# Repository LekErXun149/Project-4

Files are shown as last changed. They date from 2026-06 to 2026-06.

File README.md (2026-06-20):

# Bin Weighting System 
Weighting different type of SKU to output the correct quantity for each SKU\
Done by: Team 5
1. Gerald Goh Xuan Chee: Project Leader & Lead Software Engineer\
●	Project Management: Directed the 13-week development timeline, managed team task allocation, and ensured all system requirements met CEVA Logistics' standards.\
●	Computer Vision & AI (YOLOv8s): Took primary ownership of training the YOLOv8s model for SKU identification and configured the drivers for the dual-camera system.\
●	ROS2 Middleware Architecture: Implemented the modular ROS2 (Jazzy) node structure and the integration logic that synchronized vision data with weight inputs.
2. Lek Er Xun: Lead Mechanical Designer & Sensing Developer\
●	Precision CAD Modeling: Utilized SolidWorks to design the bin structure (MM01) and performed interference checks to ensure a seamless physical assembly.\
●	Load Cell Software Development: Authored the firmware for weight sensing, including the calibration of the 4-load-cell array and the communication protocol for the ADC modules.\
●	Rapid Prototyping: Managed the 3D printing of custom sensor mounts and spacers to ensure exact mechanical tolerances.
3. Tung Ming Xuan: Lead Validation & Fabrication Specialist\
●	System Testing & QA: Designed and executed the 50+ test cycles to verify the 1% relative accuracy and 95% SKU identification success rates.\
●	Mechanical Fabrication: Managed the manual construction and material preparation of the bin frame, ensuring the physical build matched the SolidWorks specifications.\
●	Dataset Management: Responsible for the SKU onboarding process, accurately recording the "ground truth" weights and visual profiles for the identification model.
4. Loh Sook Xian Rosalind: Procurement & Electrical Assembly Lead\
●	Electrical Hardening: Executed the soldering of the HX711 amplifier modules and core circuitry to move the project from volatile jumper wires to a permanent, vibration-resistant setup.\
●	Financial Accountability: Managed the Bill of Materials (BOM) and direct cost tracking to ensure the project stayed within the $500.00 budget.\
●	Sustainability Assessment: Conducted the evaluation of material choices and system power efficiency for the final report.
5. Alson Lim Chin Meng: Hardware Operations & Mechanical Support\
●	Hardware Environment Deployment: Responsible for the physical setup and OS configuration of the Raspberry Pi 4 to provide a stable platform for the system middleware.\
●	Power & Connectivity Management: Integrated the powered USB 3.0 hub to provide a consistent 5V supply to the cameras, preventing hardware resets.\
●	Thermal Management: Installed the active cooling system (heatsink and fan) to ensure the processor maintained performance during high-load operations.\
●	Fabrication Support: Assisted in the mechanical assembly and material cutting for the bin weighting structure.

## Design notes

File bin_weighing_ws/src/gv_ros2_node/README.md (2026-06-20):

## gv camera ros2 node

## RUN
```sh
 
ros2 launch gv_ros2 gv_camera.launch.py 

```

## 1.Dependency library

```sh
1. sudo cp ./res/50-myusb.rules /etc/udev/rules.d/
2. sudo udevadm control --reload-rules
3. sudo /etc/init.d/udev restart
4. sudo apt install libusb-1.0-0-dev libuvc-dev
5. sudo apt install libyaml-cpp-dev
```

## 2.Compile

```sh
2.1 cd gv_ros2
2.2 colcon build --packages-select gv_ros2
```

## 3.Running

```sh
3.1  . install/local_setup.sh
3.2  ros2 launch gv_ros2 gv_ros2.launch.py
```

## 4.Config params

```sh
### camera config

# set camera streams status(0 (close), 1(ir), 2(depth), 3(color), 4(ir+depth), 5(color+depth))
stream_status: 5 

# publish pointcloud
publish_pointcloud: true

# depth align to color
align_depth_to_color: false

# set camera bandwidth(0, 512,	1020,	1536,	2040,	2556,	3060)
band_width: 3060

# the max depth distance  of pointcloud
max_distance: 4.0

# show image by opencv
show_image: false

# output stream log
show_data_size: false
```
## 5.Precautions
```sh
5.1 IR data stream and depth data stream cannot be enabled at the same time.

5.2 IR data stream and color data stream cannot be enabled at the same time.
```

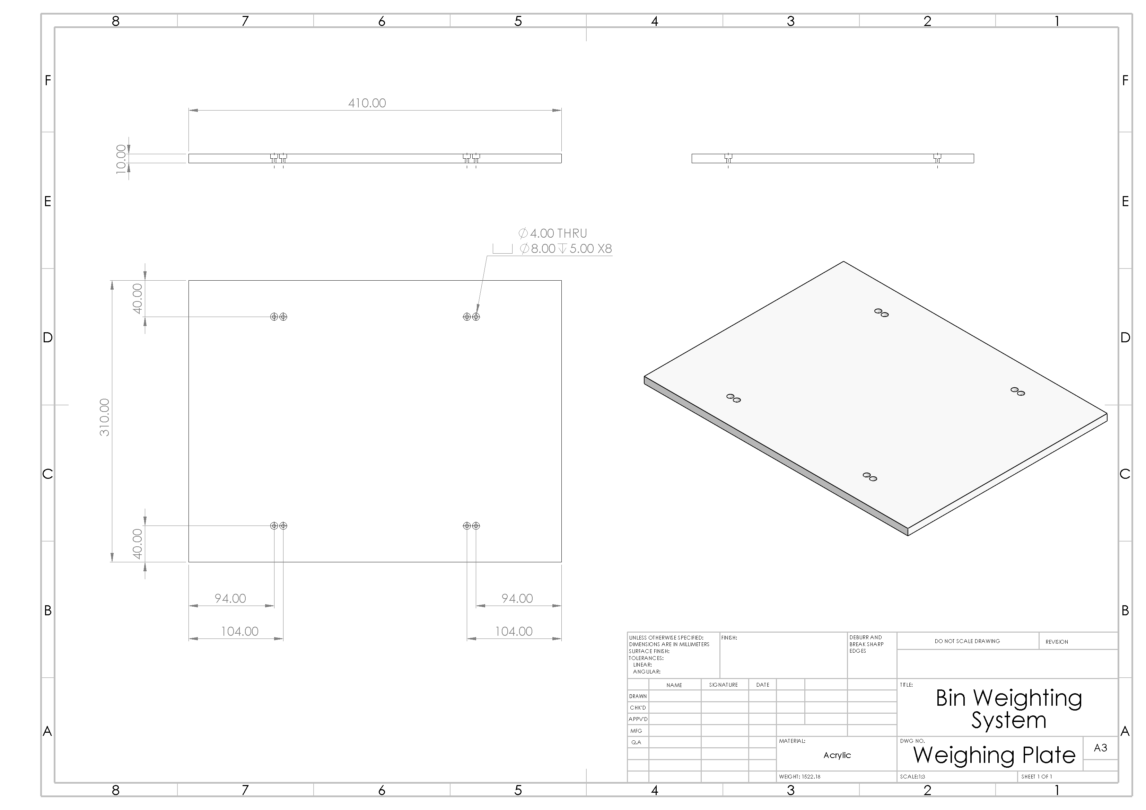
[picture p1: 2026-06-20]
CAD/Drawing/Weighing Plate.PNG

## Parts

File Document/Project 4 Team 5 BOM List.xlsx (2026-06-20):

Module: | RSE2109-Project 4 [2025/26 T2]
Done By: | Team 5
Member: | Alson Lim Chin Meng (2403433)
 | Gerald Goh Xuan Chee (2400766)
 | Lek Er Xun (2402042)
 | Loh Sook Xian Rosalind (2403415)
 | Tung Ming Xuan (2400842)
Legend
 | Unconfirmed components are highlighted in red
 | Loan components are highlighted in yellow
BOM List
 |  |  |  | Total Cost
Component NO. | Component Name | Qty | Unit Cost ($) | Direct Cost ($) | Indirect Cost ($) | Material | Size (mm) | Submitted By | Confirmed By | Remark | Component Link (Price)
MM01 | Bin Weighting Structure | NIL
MM01A01 | Focatek Depth Camera | 1 | NIL | NIL | 299.00 | NIL | NIL | Lek Er Xun | Rosalind Loh | Loan from school | NIL
MM01A02 | Raspberry Pi Camera Module 3 | 1 | 55.90 | NIL | 55.90 | NIL | NIL | Lek Er Xun | Rosalind Loh | Loan from school | Raspberry Pi Camera Module 3 (https://makersupplies.sg/products/raspberry-pi-camera-3)
MM01A03 | Load Cell Weight Sensor (5Kg) | 4 | 7.40 | 29.60 | NIL | NIL | NIL | Lek Er Xun | Tung Ming Xuan | NIL | 5Kg Load Cell Weight Sensor (https://shopee.sg/Load-Cell-1kg-5kg-10kg-20kg-i.440521573.7989384220)
MM01A03 | Load Cell Weight Sensor (5Kg) | 8 | 7.00 | 56.00 | NIL | NIL | NIL | Lek Er Xun | Tung Ming Xuan | NIL | Physical Purchase
MM01A04 | Raspberry Pi 4 Model B (8GB), 64GB SD Card, Casing with Accessory | 1 | 197.90 | NIL | 197.90 | NIL | NIL | Lek Er Xun | Rosalind Loh | Loan from school | Raspberry Pi 4 Model B (8GB) (https://shopee.sg/Raspberry-Pi-4-B-(-2GB-or-4GB-or-8GB-)-Starter-Kit-(-Power-supply-Premium-Case-Micro-SD-with-noobs-Heatsink)-i.28748863.3204168526)
MM01A05 | NAU7802 ADC Modules | 1 | 11.99 | 11.99 | NIL | NIL | NIL | Lek Er Xun | Tung Ming Xuan | NIL | NAU7802 ADC Modules (https://shopee.sg/DIYMORE-NAU7802-High-Precision-Adc-Module-24-Bit-Adc-Data-Conversion-Pressure-Module-Compatible-With-STEMMA-QT-Qwiic-i.161535507.48705037684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)
MM01A06 | HX711 ADC Modules | 1 | 7.00 | 7.00 | NIL | NIL | NIL | Lek Er Xun | Tung Ming Xuan | NIL | Physical Purchase
MM01A06 | HX711 ADC Modules | 3 | 6.00 | 18.00 | NIL | NIL | NIL | Lek Er Xun | Tung Ming Xuan | NIL | Physical Purchase
MM01A07 | ORICO 4 Port USB3.0 HUB with Power | 1 | 35.00 | 35.00 | NIL | NIL | NIL | Lek Er Xun | Rosalind Loh | NIL | ORICO 4 Port USB3.0 HUB with Power (https://shopee.sg/product/29641888/8511248406)
MM01A08 | USB-A to Type-C Cable | 1 | 7.99 | 7.99 | NIL | NIL | 1500 | Lek Er Xun | Rosalind Loh | NIL | USB-A to Type-C Cable (https://shopee.sg/Ugreen-3A-480Mbps-USB-A-to-Type-C-USB-C-Nylon-Braided-Fast-Charging-Cable-for-Phone-Fans-Tablets-i.64922680.7312481785)
MM01A09 | USB-A to Type-C Cable | 1 | 6.99 | 6.99 | NIL | NIL | 1000 |  |  |  | USB-A to Type-C Cable (https://shopee.sg/Ugreen-3A-480Mbps-USB-A-to-Type-C-USB-C-Nylon-Braided-Fast-Charging-Cable-for-Phone-Fans-Tablets-i.64922680.7312481785)
MM01A10 | Solder Breadboard | 1 | 2.00 | 2.00 | NIL | NIL | 1500 | Lek Er Xun | Rosalind Loh | NIL | Physical Purchase
MM01B01 | Plywood Sheet | 1 | 8.18 | 8.18 | NIL | Plywood | 360x410x18 | Lek Er Xun | Tung Ming Xuan | Require Sanding and drilling | Plywood Sheet (https://shopee.sg/18mm-plywood-40x50-cm-Multiplex-18-mm-50x40-cm-MC-Uty-Grade-A-Wood-Sheet-i.965491602.28063803444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)
MM01B02 | Acrylic Sheet | 1 | 39.88 | 39.88 | NIL | Acrylic | 310x410x10 | Lek Er Xun | Tung Ming Xuan | Require Sanding and drilling | Acrylic Sheet (https://shopee.sg/product/438933164/8353279058?d_id=003a3&uls_trackid=54tbj4uo00pn)
MM01C01 | Square Hollow Profile | 1 | 14.10 | NIL | 14.10 | Aluminium | 20x20x1000 | Lek Er Xun | Rosalind Loh | Loan from school | Square Hallow Profile (https://sg.misumi-ec.com/vona2/detail/110300467270?HissuCode=HFHQ2020-2-1000)
MM01C02 | T-Slot Profile | 1 | 1.04 | NIL | 1.04 | Aluminium | 20x20x200 | Lek Er Xun | Rosalind Loh | Loan from school | T-Slot Profile (https://sg.misumi-ec.com/vona2/detail/110310153359?HissuCode=LCF6-2020-200)
MM01C03 | L Bracket (Profile Mount) | 3 | 7.58 | NIL | 22.74 | Aluminium | 32x32x18 | Lek Er Xun | Rosalind Loh | Custom cut from angle bar (Scape Metal) | L Bracket (Profile Mount) (https://sg.misumi-ec.com/vona2/detail/110300544720?HissuCode=LRA3-A32-B32-L20)
MM01C04 | Hex Socket Screw (Profile Mount / Load Cell Mount) | 19 | 0.22 | NIL | 4.18 | Stainless Steel | M4x20 | Lek Er Xun | Rosalind Loh | Loan from school (3 for Profile Mount 16 for Load Cell Mount) | Hex Socket Screw (Profile Mount) (https://sg.misumi-ec.com/vona2/detail/221000551286?HissuCode=CSH-SUS-M4-20)
MM01C05 | Hex Socket Screw (Profile Mount) | 4 | 0.10 | NIL | 0.40 | Stainless Steel | M4x30 | Lek Er Xun | Rosalind Loh | Loan from school | Hex Socket Screw (Profile Mount) (https://sg.misumi-ec.com/vona2/detail/110310861029?HissuCode=E-GSCB4-30)
MM01C06 | Hex Socket Screw (Slider Mount / Depth Camera Mount) | 6 | 0.04 | NIL | 0.24 | Stainless Steel | M3x10 | Lek Er Xun | Rosalind Loh | Loan from school (4 for Slider Mount 2 for Depth Camera Mount) | Hex Socket Screw (Slider Mount) (https://sg.misumi-ec.com/vona2/detail/110310861029?HissuCode=E-GSCB3-10)
MM01C07 | Hex Socket Screw (Slider Mount) | 2 | 0.10 | NIL | 0.20 | Stainless Steel | M5x12 | Lek Er Xun | Rosalind Loh | Loan from school | Hex Socket Screw (Slider Mount) (https://sg.misumi-ec.com/vona2/detail/110310861029?HissuCode=E-GSCB5-12)
MM01C08 | Hex Socket Screw (Slider Mount / Depth Camera Mount) | 3 | 0.10 | NIL | 0.30 | Stainless Steel | M5x16 | Lek Er Xun | Rosalind Loh | Loan from school (2 for Slider Mount 1 for Depth Camera Mount) | Hex Socket Screw (Slider Mount) (https://sg.misumi-ec.com/vona2/detail/110310861029?HissuCode=E-GSCB5-16)
MM01C09 | Hex Nuts (Camera Mount) | 7 | 0.02 | NIL | 0.14 | Stainless Steel | M4x3 | Lek Er Xun | Rosalind Loh | Loan from school | Hex Nuts (Camera Mount) (https://sg.misumi-ec.com/vona2/detail/110311012769?HissuCode=E-GSLBNR4)
MM01C10 | Hex Nuts (Slider Mount) | 4 | 0.02 | NIL | 0.08 | Stainless Steel | M3x1.8 | Lek Er Xun | Rosalind Loh | Loan from school | Hex Nuts (Slider Mount) (https://sg.misumi-ec.com/vona2/detail/110311012769?HissuCode=E-GSKNTR3)
MM01C11 | T-Nuts (Slider Mount / Depth Camera Mount) | 3 | 1.25 | NIL | 3.75 | Stainless Steel | M5 | Lek Er Xun | Rosalind Loh | Loan from school (2 for Slider Mount 1 for Depth Camera Mount) | T-Nuts (Slider Mount) (https://sg.misumi-ec.com/vona2/detail/110302608140?HissuCode=SHNTU5-5)
MM01C12 | Washer (Weight Sensor) | 32 | 0.38 | NIL | 12.16 | Stainless Steel | M4x0.8 | Lek Er Xun | Rosalind Loh | Loan from school | Washer (Weight Sensor) (https://sg.misumi-ec.com/vona2/detail/110310394559?HissuCode=C-WSSA8-4-3)
MM01D01 | Profile Joint Mount | 1 | NIL | NIL | NIL | PLA | NIL | Lek Er Xun | Rosalind Loh | 3D printed | NIL
MM01D02 | Depth Camera Mount | 1 | NIL | NIL | NIL | PLA | NIL | Lek Er Xun | Rosalind Loh | 3D printed | NIL
MM01D03 | Raspberry Pi Camera Module 3 Mount | 1 | NIL | NIL | NIL | PLA | NIL | Lek Er Xun | Rosalind Loh | 3D printed | NIL
MM01D04 | HX711 ADC Modules Mount | 1 | NIL | NIL | NIL | PLA | NIL | Lek Er Xun | Rosalind Loh | 3D printed | NIL
MM01D05 | Raspberry Pi 3 Camera Mount | 1 | NIL | NIL | NIL | PLA | NIL | Lek Er Xun | Rosalind Loh | 3D printed | NIL
MM01D06 | USB Port Hub Mount | 1 | NIL | NIL | NIL | PLA | NIL | Lek Er Xun | Rosalind Loh | 3D printed | NIL
MM01E01 | Heatsink with Fan | 1 | 13.21 | 13.21 | NIL | NIL | 40x40x10 | Lek Er Xun | Rosalind Loh | NIL | Heatsink with Fan (https://shopee.sg/YSIDO-30mm-40mm-High-RPM-Fan-Powerful-Storms-Rapid-Heatsink-Metal-Cooling-With-Holder-for-1-8-1-10-1-12-ARRMA-Traxxas-HSP-RC-Car-i.500812033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)
MM01E02 | Thermal Pad | 1 | 2.49 | 2.49 | NIL | NIL | 22x70x0.5 | Lek Er Xun | Rosalind Loh | NIL | Thermal Pad (https://shopee.sg/TEUCER-M.2-SSD-Thermal-Pad-10.8W-mk-CPU-Graphics-Card-Heatsink-Motherboard-Heat-Dissipation-Silicone-Pad-70*22mm-For-SSD-i.1102234819.401531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)
MM02A01 | Bin (Small Eight Grid/375) | 1 | 13.08 | 13.08 | NIL | Plastic | 276x380x85 | Lek Er Xun | Rosalind Loh | NIL | Bin (Small Eight Grid/375) (https://shopee.sg/product/1218344199/26581424138)
MM03A01 | Storage Box | 1 | 6.32 | 6.32 | NIL | Plastic | NIL | Lek Er Xun | Rosalind Loh | NIL | Physical Purchase
MM04A01 | Scale Weights Calibration Set (1000g) | 1 | 16.24 | 16.24 | NIL | Chrome Plated Steel | NIL | Lek Er Xun | Rosalind Loh | Set with 100g, 200g, 500g weight (Total: 1000g) | Scale Weights Calibration Set (https://shopee.sg/Scale-Weights-Calibration-Tool-Set-Calibrate-100g-200g-500g-with-Box-Calibration-Weights-i.208852974.27250024832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)
MM05A01 | 15.6 Inch LCD Display | 1 | 321.07 | NIL | 321.07 | NIL | NIL | Lek Er Xun | Rosalind Loh | NIL | 15.6 Inch LCD Display (https://sg.cytron.io/c-raspberry-pi-display/p-15-6-inch-cap-touch-ips-1920-1080-hdmi-display)
MM06A01 | 7 Inch LCD Display | 1 | 57.08 | 57.08 | NIL | NIL | NIL | Lek Er Xun | Rosalind Loh | NIL | 7 Inch LCD Display (https://shopee.sg/7-Inch-Portable-Monitor-1024x600-IPS-LCD-HDMI-compatible-VGA-AV-Input-DC-Type-C-Power-Screen-for-PC-Laptop-Camera-TV-Box-DVD-i.1280323195.28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)
MM07A01 | Mini Keyboard | 1 | 14.89 | 14.89 | NIL | NIL | NIL | Lek Er Xun | Rosalind Loh | NIL | Mini Keyboard (https://shopee.sg/-SG-Local-Seller-Mini-Slim-Keyboard-Multimedia-USB-Wired-For-Notebook-Laptop-PC-Computer-i.124596143.15760342491)
MM08A01 | Heat Shrink Kit | 1 | 9.40 | 9.40 | NIL | NIL | NIL | Lek Er Xun | Rosalind Loh | NIL | Physical Purchase
MM09A01 | Double-Sided Tape | 1 | 2.18 | 2.18 | NIL | NIL | NIL | Lek Er Xun | Rosalind Loh | NIL | Physical Purchase
MM10A01 | Cable Tie | 1 | 2.18 | 2.18 | NIL | NIL | NIL | Lek Er Xun | Rosalind Loh | NIL | Physical Purchase
NIL | Product | NIL | NIL | NIL | NIL | NIL | NIL | NIL | NIL | 3D Print | Product
Total: |  |  |  | 359.70 | 933.20
 | Direct Cost (SGD$) | 359.70
 | Indirect Cost (SGD$) | 933.20
 | Total Cost (SGD$) | 1292.90

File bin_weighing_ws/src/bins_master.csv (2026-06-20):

bin_barcode | bin_type | bin_tare_weight | item_name | quantity | unit_weight
BIN001 | 8_compartment | 480 | Cream | 1 | 160
BIN001 | 8_compartment | 480
BIN001 | 8_compartment | 480
BIN001 | 8_compartment | 480
BIN001 | 8_compartment | 480
BIN001 | 8_compartment | 480
BIN001 | 8_compartment | 480
BIN001 | 8_compartment | 480
BIN002 | 8_compartment | 480
BIN002 | 8_compartment | 480
BIN002 | 8_compartment | 480
BIN002 | 8_compartment | 480
BIN002 | 8_compartment | 480
BIN002 | 8_compartment | 480
BIN002 | 8_compartment | 480
BIN002 | 8_compartment | 480
BIN003 | 8_compartment | 480
BIN003 | 8_compartment | 480
BIN003 | 8_compartment | 480
BIN003 | 8_compartment | 480
BIN003 | 8_compartment | 480
BIN003 | 8_compartment | 480
BIN003 | 8_compartment | 480
BIN003 | 8_compartment | 480
BIN004 | 8_compartment | 480
BIN004 | 8_compartment | 480
BIN004 | 8_compartment | 480
BIN004 | 8_compartment | 480
BIN004 | 8_compartment | 480
BIN004 | 8_compartment | 480
BIN004 | 8_compartment | 480
BIN004 | 8_compartment | 480
BIN005 | 8_compartment | 480 | Cream | 1 | 160
BIN005 | 8_compartment | 480
BIN005 | 8_compartment | 480
BIN005 | 8_compartment | 480
BIN005 | 8_compartment | 480
BIN005 | 8_compartment | 480
BIN005 | 8_compartment | 480
BIN005 | 8_compartment | 480

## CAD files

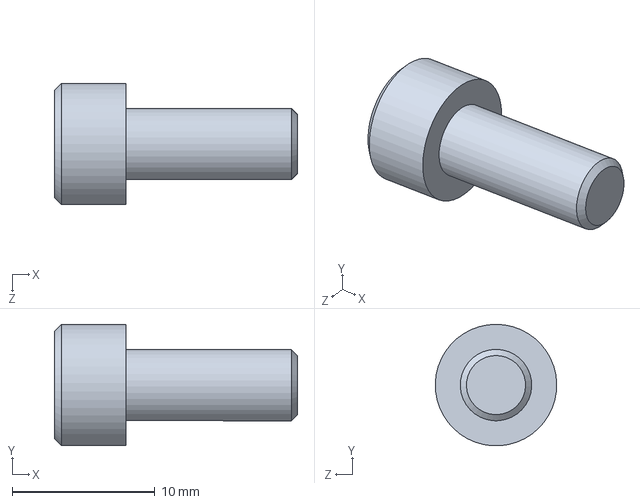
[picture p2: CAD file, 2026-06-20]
CAD/E-GSCB5-12.SLDPRT
17.0 x 8.49 x 8.49 mm

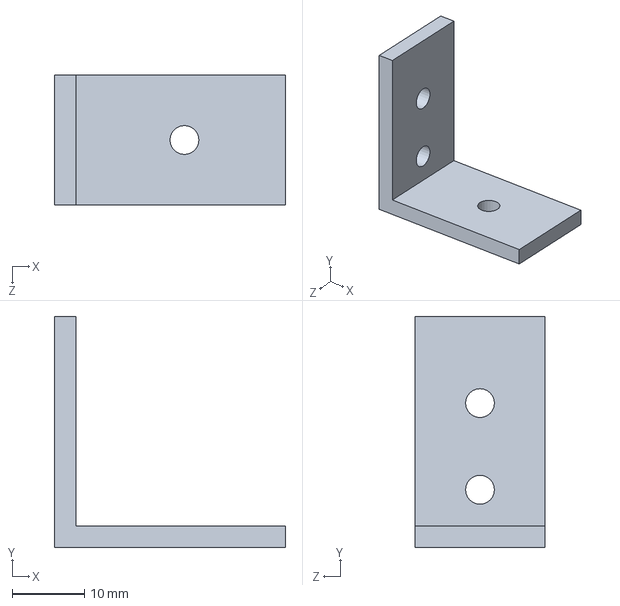
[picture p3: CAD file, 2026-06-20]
CAD/Bracket Front.SLDPRT
32.0 x 32.0 x 18.0 mm

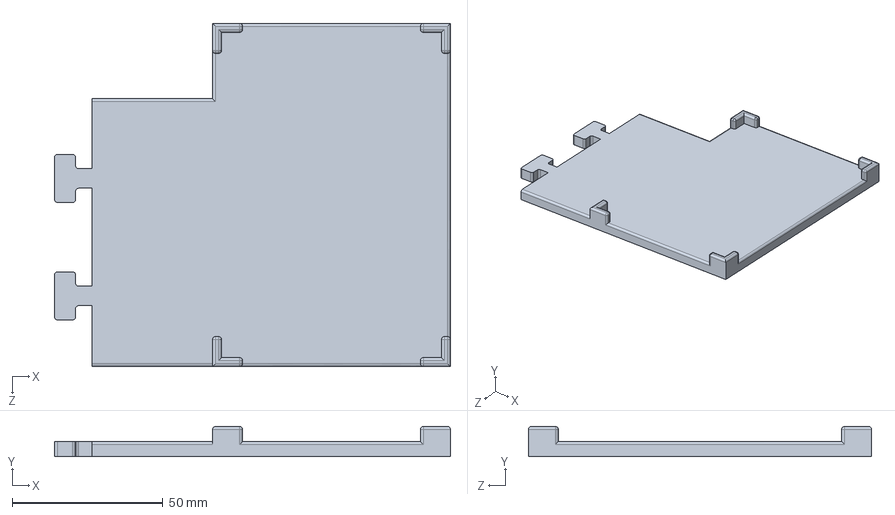
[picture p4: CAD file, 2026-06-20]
CAD/USB Port Hub Mount.SLDPRT
131.5 x 10.0 x 114.0 mm

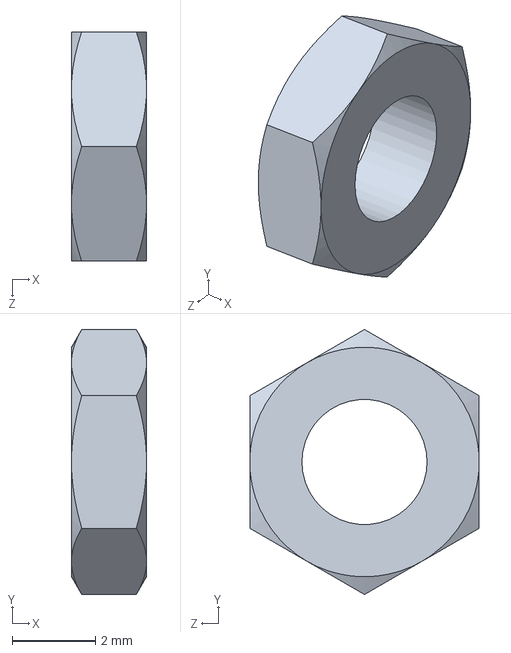
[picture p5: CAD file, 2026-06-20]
CAD/E-GSKNTR3.SLDPRT
1.80 x 6.35 x 5.50 mm

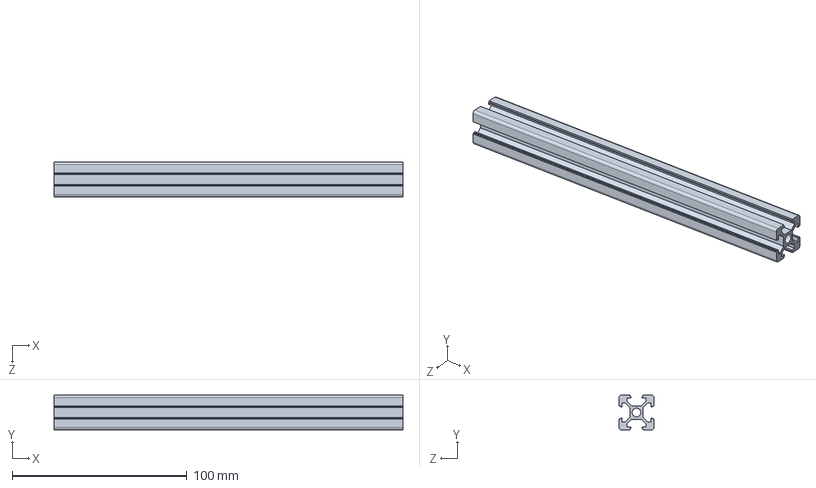
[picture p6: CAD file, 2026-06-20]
CAD/LCF6-2020-200 Profile.SLDPRT
200.0 x 20.0 x 20.0 mm

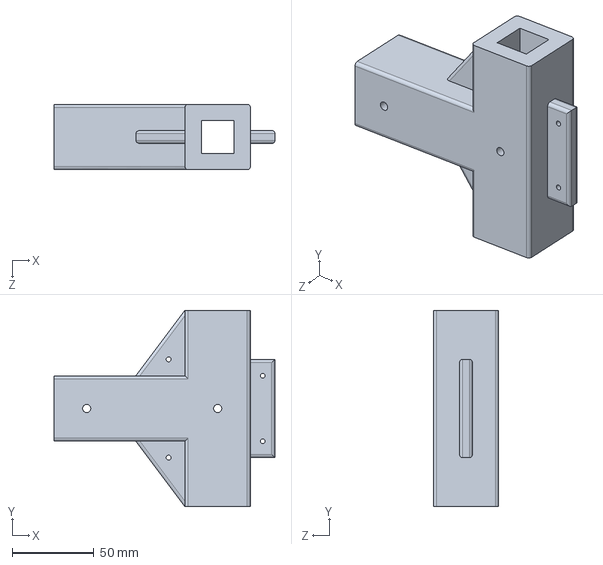
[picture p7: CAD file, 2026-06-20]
CAD/Profile Slider.SLDPRT
135.0 x 120.0 x 40.0 mm

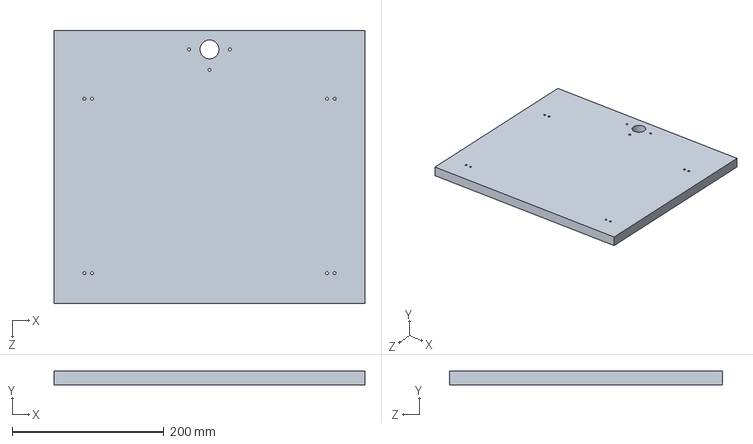
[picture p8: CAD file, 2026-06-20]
CAD/Base.SLDPRT
410.0 x 18.0 x 360.0 mm

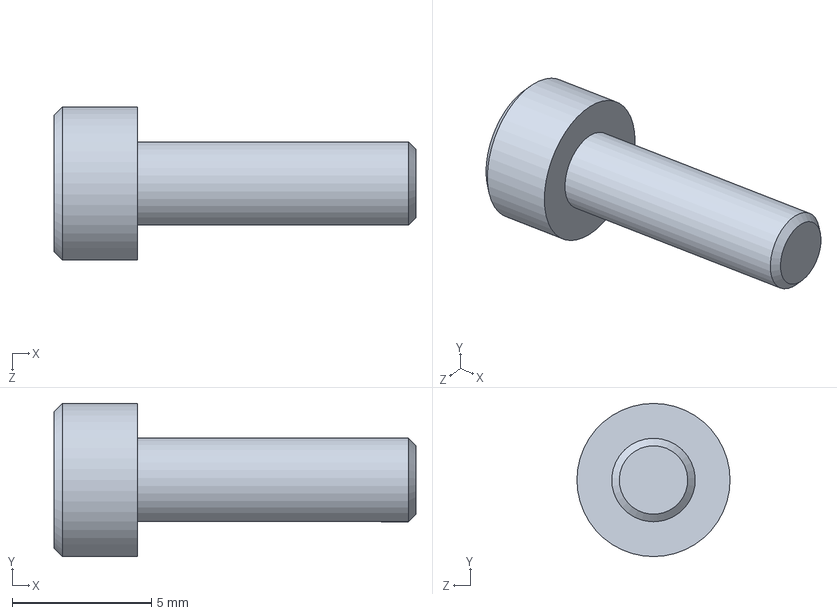
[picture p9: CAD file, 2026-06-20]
CAD/E-GSCB3-10.SLDPRT
13.0 x 5.50 x 5.50 mm

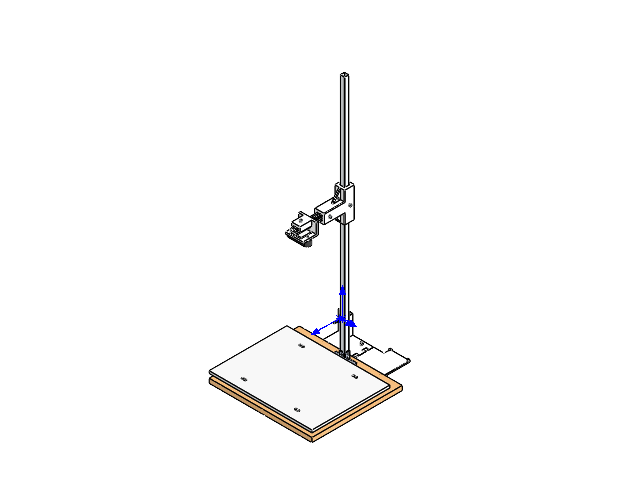
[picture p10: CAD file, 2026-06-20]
CAD/Bin Weighting System.SLDASM
Base
HFHQ2020 Profile
LCF6-2020-200 Profile
Weighing Plate
Load Cell x 4
CSH-STN-M4-20 x 19
SPWF4 Washer x 16
Bracket Front
Bracket LR x 2
E-GSCB4-30 x 4
E-GSLBNR4 x 7
Profile Slider
E-GSCB3-10 x 6
E-GSKNTR3 x 4
E-GSCB5-12 x 2
E-GSCB5-16 x 3
SHNTU5-5 x 3
Heatsink with Fan
Focatek Depth Camera
Depth Camera Bracket
Raspberry Pi 3 Camera Mount
sfw15r3ste1lf.step
Rear Components-0.step
Rear Components-1.step
Rear Components-2.step
Rear Components-3.step
Rear Components-4.step
Sensor.step
Lens.step
Ring.step
Mount.step
Housing.step
Board.step
eBom-FreeParts.step
USB Port Hub Mount

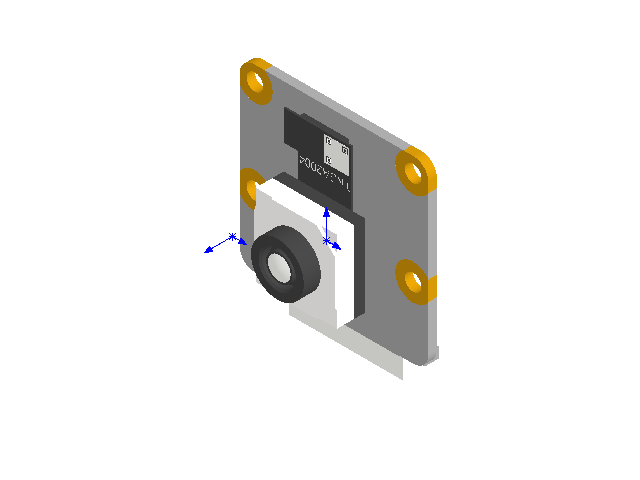
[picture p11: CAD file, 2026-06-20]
CAD/Camera Moudule 3.SLDASM
sfw15r3ste1lf.step
Rear Components-0.step
Rear Components-1.step
Rear Components-2.step
Rear Components-3.step
Rear Components-4.step
Sensor.step
Lens.step
Ring.step
Mount.step
Housing.step
Board.step
eBom-FreeParts.step

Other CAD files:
CAD/3D/Rasberry Pi Camera camera Module 3 FRONT.gcode.3mf
CAD/3D/Face Mask.gcode.3mf
CAD/3D/Hydrating Lotion.gcode.3mf
CAD/3D/Lip Tint.gcode.3mf
CAD/3D/USB Port Hub Mount.gcode.3mf
CAD/3D/Profile SIilder.gcode.3mf
CAD/3D/Raspberry Pi Camera Module 3 BACK.gcode.3mf
CAD/3D/HX711.gcode.3mf
CAD/3D/Depth Camera Bracket.gcode.3mf
CAD/3D/Raspberry Pi 3 Camera Mount.gcode.3mf
CAD/Bracket LR.SLDPRT
CAD/CSH-STN-M4-20.SLDPRT
CAD/Depth Camera Bracket.SLDPRT
CAD/Drawing/Base.SLDDRW
CAD/Drawing/Bracket Front.SLDDRW
CAD/Drawing/Bracket LR.SLDDRW
CAD/Drawing/Depth Camera Bracket.SLDDRW
CAD/Drawing/HFHQ2020 Profile.SLDDRW
CAD/Drawing/HX711 Mount.SLDDRW
CAD/Drawing/Profile Slider.SLDDRW
CAD/Drawing/Raspberry Pi 3 Camera Mount.SLDDRW
CAD/Drawing/USB Port Hub Mount.SLDDRW
CAD/Drawing/Weighing Plate.SLDDRW
CAD/E-GSCB4-30.SLDPRT
CAD/E-GSCB5-16.SLDPRT
CAD/E-GSLBNR4.SLDPRT
CAD/Face Mask.SLDPRT
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

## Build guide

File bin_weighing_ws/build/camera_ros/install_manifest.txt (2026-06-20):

/home/group5/bin_weighing_ws/install/camera_ros/lib/libcamera_component.so
/home/group5/bin_weighing_ws/install/camera_ros/share/camera_ros/cmake/camera_componentTargetsExport.cmake
/home/group5/bin_weighing_ws/install/camera_ros/share/camera_ros/cmake/camera_componentTargetsExport-noconfig.cmake

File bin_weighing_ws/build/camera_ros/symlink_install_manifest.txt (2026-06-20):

/home/group5/bin_weighing_ws/install/camera_ros/lib/camera_ros/camera_node
/home/group5/bin_weighing_ws/install/camera_ros/share/camera_ros/environment/library_path.sh
/home/group5/bin_weighing_ws/install/camera_ros/share/camera_ros/environment/library_path.dsv
/home/group5/bin_weighing_ws/install/camera_ros/share/camera_ros//launch/camera.launch.py
/home/group5/bin_weighing_ws/install/camera_ros/share/ament_index/resource_index/package_run_dependencies/camera_ros
/home/group5/bin_weighing_ws/install/camera_ros/share/ament_index/resource_index/parent_prefix_path/camera_ros
/home/group5/bin_weighing_ws/install/camera_ros/share/camera_ros/environment/ament_prefix_path.sh
/home/group5/bin_weighing_ws/install/camera_ros/share/camera_ros/environment/ament_prefix_path.dsv
/home/group5/bin_weighing_ws/install/camera_ros/share/camera_ros/environment/path.sh
/home/group5/bin_weighing_ws/install/camera_ros/share/camera_ros/environment/path.dsv
/home/group5/bin_weighing_ws/install/camera_ros/share/camera_ros/local_setup.bash
/home/group5/bin_weighing_ws/install/camera_ros/share/camera_ros/local_setup.sh
/home/group5/bin_weighing_ws/install/camera_ros/share/camera_ros/local_setup.zsh
/home/group5/bin_weighing_ws/install/camera_ros/share/camera_ros/local_setup.dsv
/home/group5/bin_weighing_ws/install/camera_ros/share/camera_ros/package.dsv
/home/group5/bin_weighing_ws/install/camera_ros/share/ament_index/resource_index/packages/camera_ros
/home/group5/bin_weighing_ws/install/camera_ros/share/ament_index/resource_index/rclcpp_components/camera_ros
/home/group5/bin_weighing_ws/install/camera_ros/share/camera_ros/cmake/ament_cmake_export_targets-extras.cmake
/home/group5/bin_weighing_ws/install/camera_ros/share/camera_ros/cmake/ament_cmake_export_dependencies-extras.cmake
/home/group5/bin_weighing_ws/install/camera_ros/share/camera_ros/cmake/camera_rosConfig.cmake
/home/group5/bin_weighing_ws/install/camera_ros/share/camera_ros/cmake/camera_rosConfig-version.cmake
/home/group5/bin_weighing_ws/install/camera_ros/share/camera_ros/package.xml

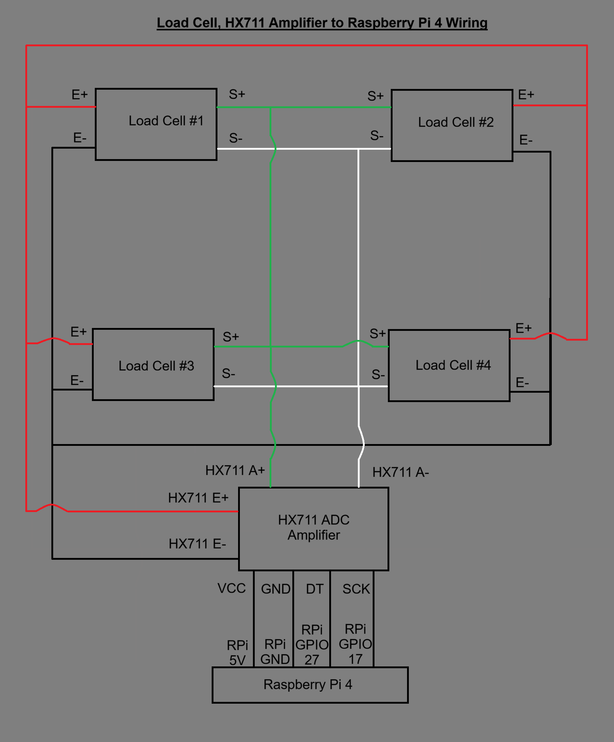
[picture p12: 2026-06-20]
CAD/Drawing/Wiring.png

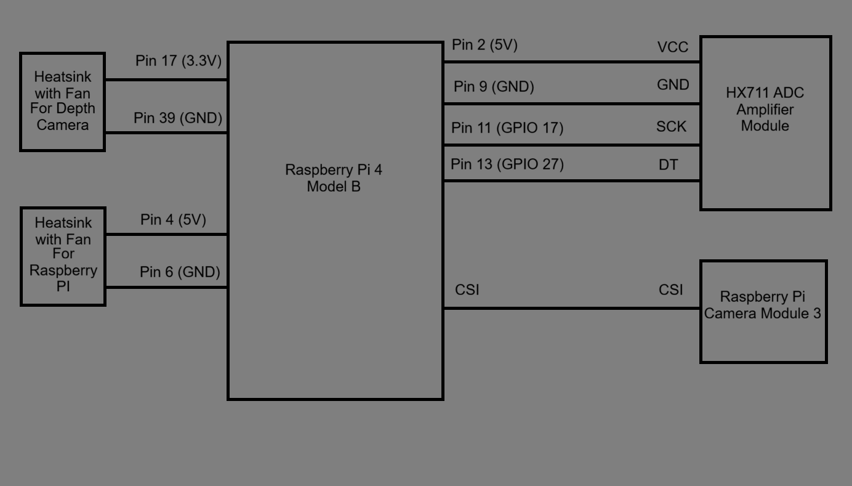
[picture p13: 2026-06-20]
CAD/Drawing/Raspberry Wiring.png

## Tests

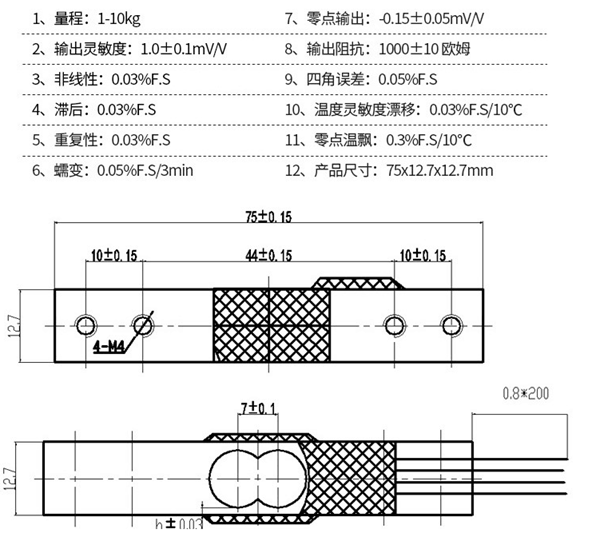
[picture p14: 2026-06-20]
Datasheet/5kg Load Cell Measurement.png

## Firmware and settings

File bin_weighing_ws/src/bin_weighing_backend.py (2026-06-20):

#!/usr/bin/env python3
"""
Bin Weighing Backend (Program 2 - ROS2 Backend)
Runs in background, handles all ROS2 operations
Communicates with manager via topics
All logging happens here (hidden from user)
"""

import rclpy
from rclpy.node import Node
from sensor_msgs.msg import Image
from std_msgs.msg import String, Float32, Float64, Empty
from cv_bridge import CvBridge
import cv2
import numpy as np
import threading
import queue
from pyzbar.pyzbar import decode, ZBarSymbol
from collections import deque
import pandas as pd
import os

# ── Class names (match your YOLO model) ──────────────────────────────────────
CLASSES = ['Foam', 'Lipgloss', 'Acid', 'Control', 'Serum', 'Cream']

# ── Model path ───────────────────────────────────────────────────────────────
MODEL_PATH = '/home/group5/best.onnx'

# ── Detection settings ───────────────────────────────────────────────────────
CONFIDENCE_THRESHOLD  = 0.45
NMS_THRESHOLD         = 0.45
INPUT_SIZE            = 640      # YOLO input size
DETECT_EVERY_N_FRAMES = 60       # Detect every 60th frame for low CPU usage

# ── Weight sampling settings ─────────────────────────────────────────────────
WEIGHT_SAMPLE_COUNT   = 70     # Higher value for better averaging after 3s stabilization
OUTLIER_STD_THRESHOLD = 2.0    # MAD threshold (2 * mad, same as calibration)
SAMPLE_RATE_HZ        = 10

# ── Bin database settings ────────────────────────────────────────────────────
BIN_DATABASE_CSV = '/home/group5/bin_weighing_ws/src/bins_master.csv'  # Path to bin database
WEIGHT_TOLERANCE_PERCENT = 2.0  # ±2% tolerance for weight matching

# Expected CSV format (multiple rows per bin for multi-SKU support):
# bin_barcode,compartment,bin_tare_weight,item_name,quantity,unit_weight
# BIN001,1,500,Acid,5,20
# BIN001,2,500,Serum,3,25
# BIN001,3,500,,,
# BIN002,1,500,Lipgloss,8,18
# Note: bin_tare_weight should be same for all rows of same bin


class WeightSampler:
    """Collects and filters weight samples"""
    
    def __init__(self, sample_count=30, outlier_threshold=2.0):
        self.samples = []
        self.sample_count = sample_count
        self.outlier_threshold = outlier_threshold
        
    def add_sample(self, weight):
        self.samples.append(weight)
    
    def is_complete(self):
        return len(self.samples) >= self.sample_count
    
    def get_progress(self):
        return (len(self.samples) / self.sample_count) * 100
    
    def get_filtered_weight(self):
        if len(self.samples) < 5:
            return None, None, []
        
        samples_array = np.array(self.samples)
        
        # Use MAD (Median Absolute Deviation) like calibration wizard
        median = np.median(samples_array)
        mad = np.median(np.abs(samples_array - median))
        
        if mad == 0:
            # All samples identical
            return median, 0.0, []
        
        # Filter using MAD (more robust than z-score)
        threshold = self.outlier_threshold * mad
        mask = np.abs(samples_array - median) < threshold
        filtered_samples = samples_array[mask]
        outliers = samples_array[~mask]
        
        if len(filtered_samples) < 5:
            # Too many outliers, return unfiltered
            return np.mean(samples_array), np.std(samples_array), []
        
        filtered_mean = np.mean(filtered_samples)
        filtered_std = np.std(filtered_samples)
        
        return filtered_mean, filtered_std, outliers.tolist()
    
    def clear(self):
        self.samples.clear()


class BinWeighingBackend(Node):
    """Backend node - handles all ROS2 operations"""
    
    def __init__(self):
        super().__init__('bin_weighing_backend')
        self.bridge = CvBridge()

        # ── Load ONNX model ──────────────────────────────────────────────────
        self.get_logger().info(f'Loading model: {MODEL_PATH}')
        self.net = cv2.dnn.readNetFromONNX(MODEL_PATH)
        self.net.setPreferableBackend(cv2.dnn.DNN_BACKEND_OPENCV)
        self.net.setPreferableTarget(cv2.dnn.DNN_TARGET_CPU)
        self.get_logger().info('Model loaded')
        
        # ── Load bin database ────────────────────────────────────────────────
        self.bin_database = self.load_bin_database()
        if self.bin_database is not None:
            self.get_logger().info(f'Loaded {len(self.bin_database)} bins from database')
        else:
            self.get_logger().warn('Bin database not loaded - weight verification disabled')

        # ── State ────────────────────────────────────────────────────────────
        self.latest_depth      = None
        self.latest_weight_raw = 0.0  # Store RAW ADC value from scale_node
        self.latest_barcode    = 'N/A'
        self.latest_detections = []
        self.frame_count       = 0
        
        # ── Sampling state ───────────────────────────────────────────────────
        self.sampling_active   = False
        self.sampler          = WeightSampler(WEIGHT_SAMPLE_COUNT, OUTLIER_STD_THRESHOLD)
        self.measurement_id   = 0  # Track each measurement uniquely
        self.measurement_stage = 'ready'  # 'ready' → 'taring' → 'tared' → 'stabilizing' → 'measuring' → 'ready'
        self.tare_reading = None  # Store tare reading from stage 1
        self.tare_samples = []  # Collect tare samples
        self.tare_sample_count = 20  # Reduced to 20 to handle slower publishing rates (~5 Hz)
        self.tare_retry_count = 0  # Track number of tare retries
        self.max_tare_retries = 2  # Maximum automatic retries before giving up

        # ── Detection thread ─────────────────────────────────────────────────
        self.frame_queue  = queue.Queue(maxsize=1)
        self.result_queue = queue.Queue(maxsize=1)
        self.detect_thread = threading.Thread(target=self.detection_loop, daemon=True)
        self.detect_thread.start()
        
        # ── Sampling timer ───────────────────────────────────────────────────
        self.sample_timer = self.create_timer(1.0 / SAMPLE_RATE_HZ, self.sample_timer_callback)
        
        # ── Stabilization check timer ────────────────────────────────────────
        # Checks if 2-second stabilization period is complete
        self.stabilization_timer = self.create_timer(0.1, self.check_stabilization)
        self.stabilization_start_time = None

        # ── Subscribers ──────────────────────────────────────────────────────
        self.color_sub = self.create_subscription(Image, '/camera0/color/image_raw', self.color_callback, 10)
        self.depth_sub = self.create_subscription(Image, '/camera0/depth/image_raw', self.depth_callback, 10)
        self.picam_sub = self.create_subscription(Image, '/camera_node/image_raw', self.barcode_callback, 10)
        
        # Subscribe to RAW weight (ADC values) for better filtering accuracy
        # scale_node must publish to /weight/raw topic
        self.weight_raw_sub = self.create_subscription(Float64, '/weight/raw', self.weight_raw_callback, 10)
        
        # Subscribe to trigger from manager
        self.trigger_sub = self.create_subscription(Empty, '/start_weighing', self.trigger_callback, 10)
        
        # Create a timer to check if we're receiving weight data
        self.create_timer(2.0, self.check_weight_data_once)
        self.weight_data_checked = False

        # ── Publishers ───────────────────────────────────────────────────────
        self.detection_pub     = self.create_publisher(Image,  '/detection/image',     10)
        self.barcode_debug_pub = self.create_publisher(Image,  '/barcode/debug_image', 10)
        self.barcode_pub       = self.create_publisher(String, '/barcode/data',        10)
        
        # Publishers for manager
        self.progress_pub = self.create_publisher(Float32, '/weighing_progress', 10)
        self.result_pub   = self.create_publisher(String,  '/weighing_result',   10)
        self.items_pub    = self.create_publisher(String,  '/current_items',     10)
        self.debug_pub    = self.create_publisher(String,  '/debug_sampling',    10)  # Debug messages

        self.get_logger().info('Backend ready')

    def trigger_callback(self, msg):
        """
        Handle trigger for 2-stage measurement:
        Stage 1 (ready): Platform empty → Take tare reading
        Stage 2 (tared): Item on platform → Measure weight
        """
        if not self.sampling_active:
            if self.measurement_stage == 'ready':
                # Stage 1: Take tare reading
                self.get_logger().info('▶ Stage 1: Taking tare reading')
                self.take_tare()
            elif self.measurement_stage == 'tared':
                # Stage 2: Measure weight
                self.get_logger().info('▶ Stage 2: Measuring weight')
                self.start_sampling()
        else:
            self.get_logger().warn('⚠ Trigger ignored - sampling already in progress')
    
    def take_tare(self):
        """Stage 1: Start tare collection (non-blocking with timeout)"""
        self.get_logger().info('  Collecting tare samples (platform should be empty)...')
        self.tare_samples = []
        self.measurement_stage = 'taring'
        self.tare_start_time = self.get_clock().now()  # Track when taring started
    
    def finish_tare(self):
        """Process tare samples with outlier filtering"""
        import statistics
        
        if not self.tare_samples:
            self.get_logger().error('  ✗ Tare failed - no samples collected!')
            self.get_logger().error('  Check if /weight/raw topic is publishing')
            self.measurement_stage = 'ready'
            return
        
        # STEP 1: Physical plausibility filter on tare samples
        # Empty platform should be between -100g and +100g (with platform mass ~500g, reading should be 450-550g range)
        # But we're more lenient: -100g to 1000g to account for platform variations
        physically_valid_tare = []
        physics_outliers_tare = []
        
        for s in self.tare_samples:
            converted = self.raw_to_weight(s)
            # Empty platform shouldn't be negative or extremely heavy
            if -100.0 <= converted <= 1000.0:
                physically_valid_tare.append(s)
            else:
                physics_outliers_tare.append(s)
        
        # Check if we have enough valid samples after physics filter
        if len(physically_valid_tare) < 10:
            self.get_logger().error(f'  ✗ Tare failed - only {len(physically_valid_tare)}/20 samples were physically valid')
            self.get_logger().error(f'  {len(physics_outliers_tare)} samples were load cell glitches')
            self.get_logger().error('  Platform may be unstable or load cell needs calibration')
            self.measurement_stage = 'ready'
            self.tare_samples = []
            
            # Notify manager of failure
            error_msg = String()
            error_msg.data = "TARE_FAILED"
            self.result_pub.publish(error_msg)
            return
        
        # STEP 2: Apply MAD outlier filtering to physically valid tare samples
        median = statistics.median(physically_valid_tare)
        mad = statistics.median([abs(s - median) for s in physically_valid_tare])
        threshold = OUTLIER_STD_THRESHOLD * mad
        
        # Filter outliers
        mad_outliers_tare = []
        valid_tare = []
        for s in physically_valid_tare:
            if mad > 0 and abs(s - median) > threshold:
                mad_outliers_tare.append(s)
            else:
                valid_tare.append(s)
        
        # Final check: need at least 10 valid samples after both filters
        if len(valid_tare) < 10:
            self.get_logger().error(f'  ✗ Tare failed - only {len(valid_tare)} valid samples after filtering')
            self.get_logger().error('  Platform too unstable - try again')
            self.measurement_stage = 'ready'
            self.tare_samples = []
            
            # Notify manager of failure
            error_msg = String()
            error_msg.data = "TARE_FAILED"
            self.result_pub.publish(error_msg)
            return
        
        # Use filtered average
        self.tare_reading = statistics.mean(valid_tare)
        std = statistics.stdev(valid_tare) if len(valid_tare) > 1 else 0
        
        total_tare_outliers = len(physics_outliers_tare) + len(mad_outliers_tare)
        
        self.get_logger().info(f'  ✓ Tare complete: {self.tare_reading:.0f} ADC (±{std:.0f})')
        if total_tare_outliers > 0:
            self.get_logger().info(f'  Removed {total_tare_outliers} outlier samples ({len(physics_outliers_tare)} physics, {len(mad_outliers_tare)} MAD)')
        
        # Check tare quality and warn user if poor
        outlier_percentage = (total_tare_outliers / len(self.tare_samples)) * 100
        quality_warning = False
        
        if outlier_percentage > 30:  # More than 30% outliers
            self.get_logger().warn('=' * 70)
            self.get_logger().warn('⚠️  TARE QUALITY WARNING')
            self.get_logger().warn('=' * 70)
            self.get_logger().warn(f'Removed {total_tare_outliers}/20 samples ({outlier_percentage:.0f}% outliers)')
            self.get_logger().warn('Platform appears unstable - tare quality is POOR')
            self.get_logger().warn('This will affect measurement accuracy!')
            self.get_logger().warn('=' * 70)
            quality_warning = True
        elif std > 500:  # High standard deviation
            self.get_logger().warn('=' * 70)
            self.get_logger().warn('⚠️  TARE QUALITY WARNING')
            self.get_logger().warn('=' * 70)
            self.get_logger().warn(f'Standard deviation: ±{std:.0f} ADC (high instability)')
            self.get_logger().warn('Platform readings are not stable')
            self.get_logger().warn('This will affect measurement accuracy!')
            self.get_logger().warn('=' * 70)
            quality_warning = True
        
        # GENERATE DEBUG OUTPUT FOR STAGE 1 (TARE)
        debug_lines = []
        debug_lines.append(f'DEBUG: STAGE 1 - TARE')
        debug_lines.append(f'(Two-stage filtering: 1) Physics check, 2) MAD outlier removal)')
        debug_lines.append('')
        
        debug_lines.append(f'Total tare samples collected: {len(self.tare_samples)}')
        debug_lines.append('')
        
        # Show all tare samples with markers
        debug_lines.append('ALL tare samples (RAW ADC):')
        for i, s in enumerate(self.tare_samples):
            converted = self.raw_to_weight(s)
            is_physics_outlier = s in physics_outliers_tare
            is_mad_outlier = s in mad_outliers_tare
            if is_physics_outlier:
                marker = '[PHYSICS OUTLIER]'
            elif is_mad_outlier:
                marker = '[MAD OUTLIER]'
            else:
                marker = '✓'
            debug_lines.append(f'  {marker:20s} Sample {i+1:2d}: RAW={s:.0f}  →  {converted:8.2f}g')
        
        # Statistics (on ALL samples before filtering)
        debug_lines.append('')
        debug_lines.append('Tare statistics (before filtering):')
        debug_lines.append(f'  Mean: {statistics.mean(self.tare_samples):.0f} ADC')
        debug_lines.append(f'  Median: {statistics.median(self.tare_samples):.0f} ADC')
        debug_lines.append(f'  Std Dev: {statistics.stdev(self.tare_samples) if len(self.tare_samples) > 1 else 0:.0f} ADC')
        debug_lines.append(f'  Min: {min(self.tare_samples):.0f} ADC')
        debug_lines.append(f'  Max: {max(self.tare_samples):.0f} ADC')
        debug_lines.append(f'  Range: {max(self.tare_samples) - min(self.tare_samples):.0f} ADC')
        
        # Physics filtering info
        debug_lines.append('')
        debug_lines.append('STEP 1: Physical Plausibility Filter (Tare)')
        debug_lines.append(f'  Valid range: -100g to 1000g (empty platform with variations)')
        debug_lines.append(f'  Physics outliers removed: {len(physics_outliers_tare)}')
        debug_lines.append(f'  Physically valid samples: {len(physically_valid_tare)}/{len(self.tare_samples)}')
        
        # MAD filtering info on physically valid samples
        debug_lines.append('')
        debug_lines.append('STEP 2: MAD Outlier Detection (on physically valid tare samples)')
        debug_lines.append(f'  Median: {median:.0f} ADC')
        debug_lines.append(f'  MAD: {mad:.0f} ADC')
        debug_lines.append(f'  Threshold: ±{threshold:.0f} ADC')
        debug_lines.append(f'  MAD outliers removed: {len(mad_outliers_tare)}')
        
        # Valid samples used
        debug_lines.append('')
        debug_lines.append(f'Final valid tare samples (after both filters - {len(valid_tare)} total):')
        for i, s in enumerate(valid_tare[:10]):  # Show first 10
            converted = self.raw_to_weight(s)
            debug_lines.append(f'  ✓ Valid {i+1:2d}: RAW={s:.0f}  →  {converted:.2f}g')
        if len(valid_tare) > 10:
            debug_lines.append(f'  ... and {len(valid_tare) - 10} more valid samples')
        
        # Summary
        debug_lines.append('')
        debug_lines.append('=' * 80)
        debug_lines.append('TARE SUMMARY:')
        debug_lines.append('=' * 80)
        debug_lines.append(f'Tare reading:  {self.tare_reading:.0f} ADC  →  {self.raw_to_weight(self.tare_reading):.2f}g')
        debug_lines.append(f'Stability:     ±{std:.0f} ADC')
        debug_lines.append(f'Physics outliers: {len(physics_outliers_tare)} (load cell glitches)')
        debug_lines.append(f'MAD outliers:     {len(mad_outliers_tare)} (statistical outliers)')
        debug_lines.append(f'Total outliers:   {total_tare_outliers}/{len(self.tare_samples)} removed')
        debug_lines.append(f'Valid samples: {len(valid_tare)}/{len(self.tare_samples)} (minimum 10 required)')
        if std < 100:
            debug_lines.append(f'Quality:       ✓ EXCELLENT (Std Dev < 100)')
        elif std < 500:
            debug_lines.append(f'Quality:       ✓ GOOD (Std Dev < 500)')
        elif std < 1000:
            debug_lines.append(f'Quality:       ⚠ FAIR (Std Dev < 1000)')
        else:
            debug_lines.append(f'Quality:       ✗ POOR (Std Dev > 1000) - Check platform stability')
        debug_lines.append('=' * 80)
        
        # Publish debug data for Stage 1
        debug_msg = String()
        debug_msg.data = '\n'.join(debug_lines)
        self.debug_pub.publish(debug_msg)
        
        # Small delay to ensure debug message is sent
        import time
        time.sleep(0.05)
        
        # Move to stage 2
        self.measurement_stage = 'tared'
        self.tare_retry_count = 0  # Reset retry counter on success
        self.get_logger().info('  Ready for Stage 2: Place item and press ENTER')
        
        # Publish a simple result to unblock the manager
        # (manager is waiting for a result after pressing ENTER)
        result_msg = String()
        result_msg.data = "TARE_COMPLETE"
        self.result_pub.publish(result_msg)
        
        # Small delay to ensure message is transmitted
        import time
        time.sleep(0.1)
    
    def start_sampling(self):
        """Stage 2: Start weight sampling (after 3-second stabilization)"""
        self.get_logger().info('  Waiting 3 seconds for platform to stabilize...')
        
        # Set state to measuring with delay
        self.measurement_stage = 'stabilizing'
        self.stabilization_start_time = self.get_clock().now()
    
    def check_stabilization(self):
        """Check if 3-second stabilization period is complete"""
        if self.measurement_stage == 'stabilizing':
            elapsed = (self.get_clock().now() - self.stabilization_start_time).nanoseconds / 1e9
            
            if elapsed >= 3.0:  # 3 seconds for better balance of speed and stability
                # Stabilization complete, start actual sampling
                self.sampler.clear()
                self.measurement_id += 1
                self.sampling_active = True
                self.measurement_stage = 'measuring'
                
                self.get_logger().info(f'✓ Sampling started - Measurement #{self.measurement_id}')
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

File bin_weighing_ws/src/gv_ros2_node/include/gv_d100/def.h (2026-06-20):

#pragma once

//#include <QtEndian>
#include<string.h>

typedef unsigned char       uint8_t;
typedef unsigned short      uint16_t;
typedef unsigned int        uint32_t;

typedef signed char         int8_t;
typedef signed short        int16_t;
typedef signed int          int32_t;

#define USB_TIMEOUT		500//3000

#define SUCCESS          0 
#define EPARAM          -1 
#define ESETCFG         -2 
#define ECLAIMINF       -3 
#define EWRITE          -4 
#define EREAD           -5 
#define EOPEN           -6 
#define ECONFIG         -7 
#define ECALC			-8


#define BUF_1M_LEN				(1 * 1024 * 1024)						/* 1M */ 
#define BUF_5M_LEN				(5 * 1024 * 1024)                       /*5M*/
#define BUF_10M_LEN				(10 * 1024 * 1024)						/* 10M */ 
#define BUF_20M_LEN				(20 * 1024 * 1024)						/* 20M */ 

#define FRAME_LEN				512		//每一个报文长度
#define DATA_PER_LEN			(FRAME_LEN-CRC_LEN-HEAD_LEN)   //bin部分实际长度
#define CRC_LEN					0x04    //CRC长度
#define HEAD_LEN				12    //头长

#define FIXED_BURNING_SIZE				(4*1024)   //4K

#define EXTENT_LEN		16
#define BIN_HEAD_LEN	16


//握手
#define USB_UPGRADE_CONNECT_SEND_CMD	0x10    
#define USB_UPGRADE_CONNECT_ACK_CMD		0x30
//数据总长度信息
#define USB_UPGRADE_SEND_BIN_LEN_CMD	0x11
#define USB_UPGRADE_ACK_BIN_LEN_CMD		0x31
//发送固件
#define USB_UPGRADE_SEND_BIN_CMD		0x12	//发送
#define USB_UPGRADE_ACK_BIN_OK_CMD		0x32    //成功接收
//开始烧录
#define USB_UPGRADE_PROGRAMMER_BIN_CMD	0x13    
#define USB_UPGRADE_PROGRAMMER_OK_CMD	0x33    //烧录成功
//烧录完成，不再烧录的时候进行复位
#define USB_UPGRADE_RESET_SEND_CMD		0x14    //发送复位
#define USB_UPGRADE_RESET_OK_CMD		0x34    //执行复位
//读取板子数据
#define USB_READ_PROGRAMMER_BIN_CMD		0x15	//读取板子数据指令
#define USB_READ_PROGRAMMER_OK_CMD		0x35    //板子返回的数据

//请求算法系数
#define USB_CALC_FACTOR					0xFC	
//关闭AE和IR-LED
#define USB_BD_CLOSE_AE_IR				0xF7
//IR current Value Gears
#define USB_IR_CURRENT_GEAR				0xF8
//关闭IR
#define USB_CLOSE_IR					0xF9
// 读取写入SN
#define USB_RD_WR_SN					0xFA

#define USB_IMAGE_CHANNEL				0xFE
#define USB_SLAVE_SENSOR_STANDBY		0xFF
#define USB_SLAVE_SENSOR_STEAMING		0xE0

#define USB_CK805_ENTER_TWEAKING_MODE	0xE1
#define USB_CK805_PARAM_TWEAK			0xE2
#define USB_FRAMERATE_ADJUST			0xE3		//设置帧率
#define USB_OBTAIN_SOFTVERSION			0xE4		// 获取编译器版本
#define USB_RGB_RESOLUTION				0xE5		// RGB分辨率设置
#define USB_RGB_CALIB_MODE				0xE6		// 设置RGB标定模式

#define USB_RW_CALIBRATION_PARAMS_IR_IR		0xE8
#define USB_RW_CALIBRATION_PARAMS_IR_RGB	0xE9

#define USB_ISP_EXPOSURE_CONTROL			0xA1
#define USB_ISP_WB_CONTROL					0xA2
#define USB_ISP_CPROC_CONTROL				0xA3
#define USB_ISP_SHARPNESS_CONTROL			0xA4
#define USB_ISP_GAMMA_CONTROL				0xA5

#define USB_PACKET_LEN						0xDF

#define HARDWARE_RESTART					0x99

#define G_BASE_ADDR 0xBA7000	//双目偏移地址

#define DATA_LEN 0x08


#pragma pack(1)


//发送的头 PC->510
struct send_pack_head_t {
	send_pack_head_t()
	{
		head[0] = 'A';
		head[1] = 'B';
		head[2] = 'H';
		cmd = 0;
		nDataSize = 0;
	}
	uint8_t head[3];
	uint8_t cmd;
	uint32_t nAddr;			//烧录时是地址，命令时就是指令
	uint32_t nDataSize;

	uint32_t FromBigEndian1(uint32_t data)
	{
		uint32_t result_val;

		result_val = (data & 0xff) << 24;
		result_val |= ((data >> 8) & 0xff) << 16;
		result_val |= ((data >> 16) & 0xff) << 8;
		result_val |= (data >> 24) & 0xff;

		return result_val;
	}

	void ready()
	{
		nAddr = FromBigEndian1(nAddr);
		nDataSize = FromBigEndian1(nDataSize);
	}
};

//接收数据的协议的帧头 510->PC
 struct recv_pack_head_t {
	recv_pack_head_t()
	{
		head[0] = 'A';
		head[1] = 'B';
		head[2] = 'H';
		cmd = 0;
		result = 0;
		nAddr = 0;
		nDataSize = 0;
	}
	uint8_t head[3];
	uint8_t cmd;  
	uint8_t result;
	uint32_t nAddr;
	uint32_t nDataSize;	
	//uint8_t checkSum;

	uint32_t FromBigEndian1(uint32_t data)
	{
		uint32_t result_val;

		result_val = (data & 0xff) << 24;
		result_val |= ((data >> 8) & 0xff) << 16;
		result_val |= ((data >> 16) & 0xff) << 8;
		result_val |= (data >> 24) & 0xff;

		return result_val;
	}

	void ready()
	{
		nAddr = FromBigEndian1(nAddr);
		nDataSize = FromBigEndian1(nDataSize);
	}
};

 //16字节对齐头
 struct bin_head_t {
	 uint8_t magic[4];
	 uint8_t load_addr[4];
	 uint8_t img_len[4];
	 uint8_t res[4];
 };

 struct Sub_Header_t
 {
	 uint8_t nSerial;		//序号
	 uint32_t nMsgSize;		//报文大小
 };

struct Calibration_Param_t
{
	double cx;
	double cy;
	double focus;
	double baseLine;
};

//重影误差
struct Calibration_Error_t
{
	float err_1;
	float err_2;
};

//数据总长度信息
struct Data_Len_t
{
	Data_Len_t()
	{
		nAddr = 0;
		nDataLen = 0;
	}
	uint32_t nAddr;			//数据地址
	uint32_t nDataLen;		//数据长度

	uint32_t FromBigEndian1(uint32_t data)
	{
		uint32_t result_val;

		result_val = (data & 0xff) << 24;
		result_val |= ((data >> 8) & 0xff) << 16;
		result_val |= ((data >> 16) & 0xff) << 8;
		result_val |= (data >> 24) & 0xff;

		return result_val;
	}

	void ready()
	{
		nAddr = FromBigEndian1(nAddr);
		nDataLen = FromBigEndian1(nDataLen);
	}
};
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

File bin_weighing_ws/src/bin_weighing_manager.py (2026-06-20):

#!/usr/bin/env python3
"""
Bin Weighing Manager (Program 1 - User Interface)
Clean terminal interface for user interaction
Handles:
  - Calibration checking and prompting
  - User trigger for weighing
  - Display results clearly
  - No ROS2 logging spam
"""

import rclpy
from rclpy.node import Node
from std_msgs.msg import String, Float32, Bool, Empty
from std_srvs.srv import Trigger
import sys
import os
import json
import subprocess
from datetime import datetime

# ── Calibration settings ─────────────────────────────────────────────────────
CALIBRATION_FILE = '/root/.ros/hx711_calibration.json'
CALIBRATION_MAX_AGE_HOURS = 2

# ANSI color codes
RED = '\033[91m'
GREEN = '\033[92m'
YELLOW = '\033[93m'
CYAN = '\033[96m'
BOLD = '\033[1m'
RESET = '\033[0m'


def clear_screen():
    """Clear terminal screen"""
    os.system('clear' if os.name != 'nt' else 'cls')


def print_header():
    """Print application header"""
    clear_screen()
    print(f"{CYAN}{'=' * 80}{RESET}")
    print(f"{BOLD}{CYAN}BIN WEIGHING SYSTEM{RESET}")
    print(f"{CYAN}{'=' * 80}{RESET}\n")


def check_calibration_age():
    """Check if calibration file exists and is recent"""
    if not os.path.exists(CALIBRATION_FILE):
        return False, False, None, None
    
    try:
        with open(CALIBRATION_FILE, 'r') as f:
            cal_data = json.load(f)
        
        file_mtime = os.path.getmtime(CALIBRATION_FILE)
        cal_datetime = datetime.fromtimestamp(file_mtime)
        age = datetime.now() - cal_datetime
        age_hours = age.total_seconds() / 3600
        
        is_recent = age_hours <= CALIBRATION_MAX_AGE_HOURS
        
        return True, is_recent, age_hours, cal_data
        
    except Exception as e:
        print(f"{RED}Error reading calibration: {e}{RESET}")
        return False, False, None, None


def startup_calibration_check():
    """Check calibration and prompt user if needed"""
    
    exists, is_recent, age_hours, cal_data = check_calibration_age()
    
    if not exists:
        print(f"{RED}✗ CALIBRATION MISSING!{RESET}")
        print(f"{YELLOW}  Location: {CALIBRATION_FILE}{RESET}")
        print(f"{RED}  Scale must be calibrated before use.{RESET}")
        print(f"\n{YELLOW}⚠️  WARNING: System will use TEST calibration as fallback{RESET}")
        print(f"{YELLOW}  Measurements will be INACCURATE and FOR TESTING ONLY!{RESET}\n")
        
        response = input(f"{BOLD}{CYAN}>>> Launch calibration wizard? (yes/no): {RESET}").strip().lower()
        
        if response in ['yes', 'y']:
            launch_calibration()
            exists, is_recent, age_hours, cal_data = check_calibration_age()
        else:
            print(f"\n{RED}⚠️  Continuing in TEST MODE - readings are NOT accurate!{RESET}\n")
    
    elif not is_recent:
        print(f"{GREEN}✓ Calibration file found{RESET}")
        print(f"  Age: {age_hours:.1f} hours old")
        print(f"  {YELLOW}⚠  Older than {CALIBRATION_MAX_AGE_HOURS} hours - recalibration recommended{RESET}\n")
        
        response = input(f"{BOLD}{CYAN}>>> Launch calibration wizard? (yes/no): {RESET}").strip().lower()
        
        if response in ['yes', 'y']:
            launch_calibration()
        else:
            print(f"\n{YELLOW}Using existing calibration{RESET}\n")
    
    else:
        print(f"{GREEN}✓ Calibration OK ({age_hours:.1f} hours old){RESET}\n")
    
    input(f"{CYAN}Press ENTER to start weighing system...{RESET}")


def launch_calibration():
    """Launch calibration wizard and reload"""
    print(f"\n{CYAN}Launching calibration wizard...{RESET}\n")
    
    try:
        # Need sudo for GPIO access
        result = subprocess.run([
            'sudo', 'bash', '-c',
            'source /opt/ros/jazzy/setup.bash && '
            'source /home/group5/bin_weighing_ws/install/setup.bash && '
            'ros2 run hx711_scale calibration_node'
        ])
        
        if result.returncode == 0:
            print(f"\n{GREEN}✓ Calibration complete!{RESET}")
            print(f"{CYAN}Reloading calibration in scale node...{RESET}")
            
            # Reload calibration in running scale node
            subprocess.run([
                'ros2', 'service', 'call', '/reload_calibration', 'std_srvs/srv/Trigger'
            ], capture_output=True, timeout=5)
            
            print(f"{GREEN}✓ Calibration reloaded{RESET}\n")
        else:
            print(f"{YELLOW}⚠  Calibration failed (exit code {result.returncode}){RESET}\n")
        
    except Exception as e:
        print(f"{YELLOW}⚠  Calibration error: {e}{RESET}\n")
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

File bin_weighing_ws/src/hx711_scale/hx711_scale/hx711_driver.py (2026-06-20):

"""
HX711 Hardware Driver
Low-level interface to HX711 ADC
"""

import RPi.GPIO as GPIO
import time
import statistics
from typing import List, Tuple, Optional


class HX711Driver:
    """Hardware driver for HX711 24-bit ADC"""
    
    def __init__(self, dout_pin: int = 27, sck_pin: int = 17, gain: int = 128):
        """
        Initialize HX711
        
        Args:
            dout_pin: GPIO pin for data (default: 27)
            sck_pin: GPIO pin for clock (default: 17)
            gain: Amplifier gain - 128 (Ch A), 64 (Ch A), 32 (Ch B)
        """
        self.DOUT = dout_pin
        self.SCK = sck_pin
        self.GAIN = 1 if gain == 128 else (3 if gain == 32 else 2)
        
        # Calibration parameters
        self.offset = 0.0
        self.scale = 1.0
        
        # Initialize GPIO
        GPIO.setmode(GPIO.BCM)
        GPIO.setup(self.SCK, GPIO.OUT)
        GPIO.setup(self.DOUT, GPIO.IN)
        GPIO.output(self.SCK, False)
        
        # Power cycle
        self._power_cycle()
        
        # Flush initial readings
        for _ in range(5):
            self.read_raw()
            time.sleep(0.1)
    
    def _power_cycle(self):
        """Power cycle the HX711"""
        GPIO.output(self.SCK, True)
        time.sleep(0.1)
        GPIO.output(self.SCK, False)
        time.sleep(1)
    
    def is_ready(self) -> bool:
        """Check if HX711 has data ready"""
        return GPIO.input(self.DOUT) == 0
    
    def read_raw(self, timeout: float = 1.0) -> Optional[int]:
        """
        Read raw 24-bit value from HX711
        
        Args:
            timeout: Maximum time to wait for ready (seconds)
            
        Returns:
            Raw signed 24-bit value, or None if timeout
        """
        # Wait for ready
        start_time = time.time()
        while not self.is_ready():
            if time.time() - start_time > timeout:
                return None
            time.sleep(0.001)
        
        # Read 24 bits (no delays for RPi timing)
        value = 0
        for _ in range(24):
            GPIO.output(self.SCK, True)
            value = (value << 1) | GPIO.input(self.DOUT)
            GPIO.output(self.SCK, False)
        
        # Send gain pulses
        for _ in range(self.GAIN):
            GPIO.output(self.SCK, True)
            GPIO.output(self.SCK, False)
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
